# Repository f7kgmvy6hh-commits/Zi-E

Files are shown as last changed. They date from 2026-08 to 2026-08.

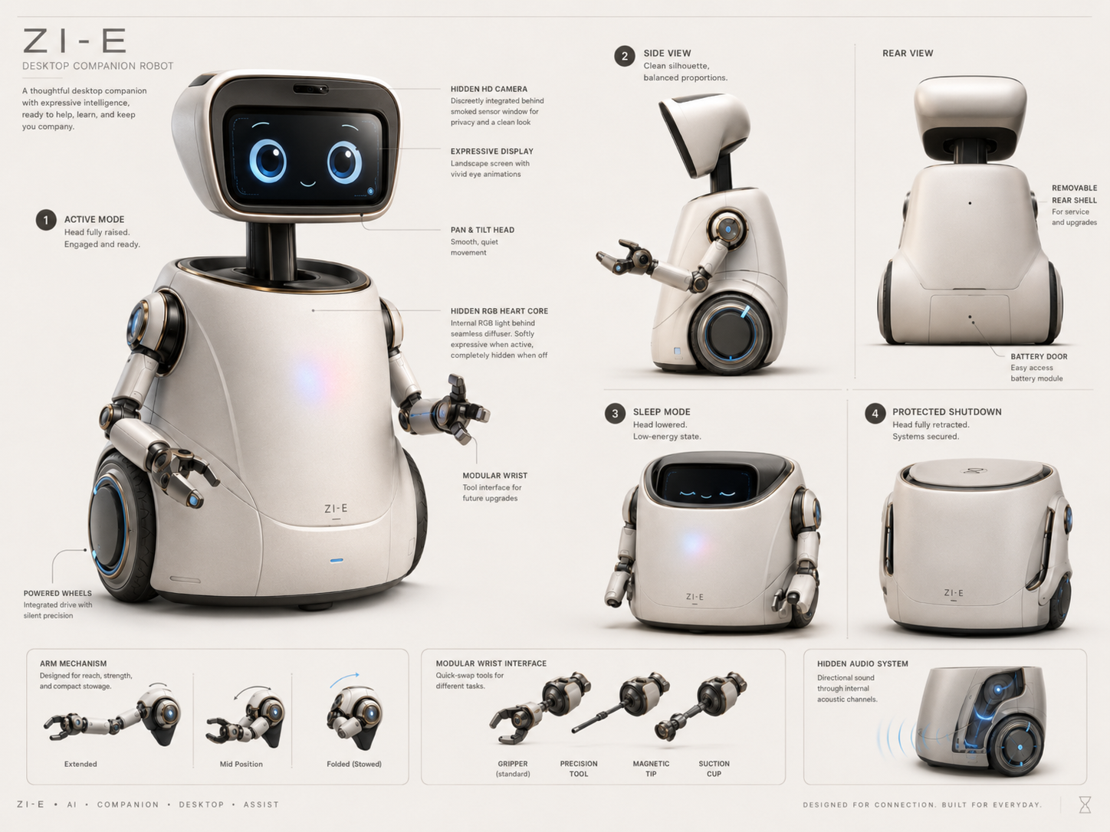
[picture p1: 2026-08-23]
assets/concepts/ZI-E_early_concept_board.png

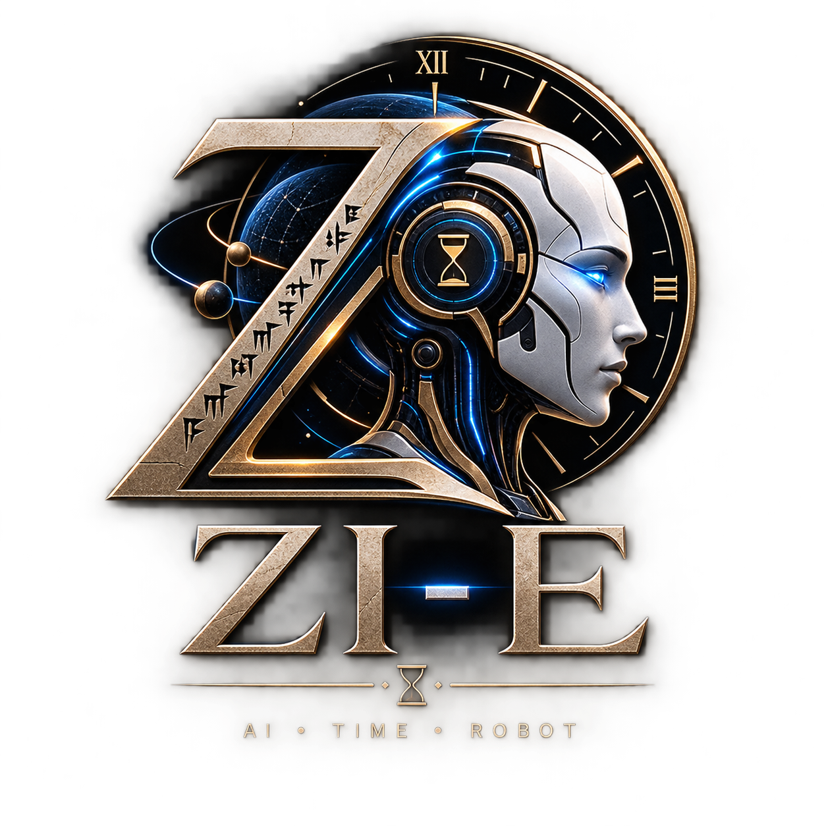
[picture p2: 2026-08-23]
assets/branding/ZI-E_AI_Time_Robot_Emblem.png

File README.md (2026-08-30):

# Zi-E

Zi-E is a modular desktop AI companion robot under active engineering development.
The repository contains the HostRuntime and Control Center foundations, bounded
semantic protocols, a physically inert ESP32-S3 Presence target, host-testable
firmware contracts, hardware evidence, and safety/commissioning gates.

## Current status

- Control Center: App 0.05, evidence-driven engineering cockpit.
- HostRuntime: development foundation and tests are active.
- ESP32-S3: the official ESP-IDF v6.0.2 generic Presence target cross-build passes.
- ESP32 physical binding: disabled; HW-002 has not arrived and is unverified.
- ESP32 flashing: not authorized and absent from the generic build workflow.
- STM32: official toolchain and physical target remain incomplete.
- Phase2B2: WAITING_FOR_VERIFIED_INPUTS.
- Physical commissioning: NOT_STARTED; first integrated power is NOT_AUTHORIZED.

See [Current State](docs/CURRENT_STATE.md) for the exact software and hardware truth.

## Architecture

```text
HostRuntime / AI brain
        authenticated, bounded semantic protocol
ESP32-S3 Presence Runtime
        bounded semantic controller-link boundary
STM32 Safety / Motion Authority
```

HostRuntime owns AI, planning, memory, providers, Hermes integration, semantic
coordination, and the Control Center. ESP32 owns the future network/media/face edge
but no final motion authority. STM32 owns motors, actuators, encoders, limits,
cliff/bumper/current supervision, E-stop, Motion Kill, safe stop, and final physical
motion acceptance or rejection.

A connection never grants motion authority. ACCEPTED does not mean EXECUTED. Face
behavior cannot originate movement. STOP/FREEZE/EMERGENCY_STOP remain deterministic,
bounded safety observations; physical stop confirmation belongs to the protected
STM32 path.

## Quick start

Windows setup creates a local virtual environment and a random bearer token in the
Git-ignored .env file:

```powershell
powershell -ExecutionPolicy Bypass -File .\scripts\setup.ps1
powershell -ExecutionPolicy Bypass -File .\scripts\start.ps1
```

The Control Center opens on the configured loopback address (default
http://127.0.0.1:8766/). The bearer token stays in page memory only; it is not stored
by the browser.

Run the App and script test suite:

```powershell
.\.venv\Scripts\python.exe -m pytest tests\app tests\scripts -q
.\.venv\Scripts\python.exe .\scripts\run_tests_fallback.py
```

Run the host firmware configure/build/tests with the fixed workflow:

```powershell
powershell -ExecutionPolicy Bypass -File .\scripts\firmware-workflow.ps1 -Action host-configure
powershell -ExecutionPolicy Bypass -File .\scripts\firmware-workflow.ps1 -Action host-test
```

Run the official generic ESP32-S3 build from an EIM-activated ESP-IDF environment:

```powershell
cd "C:\Users\mohamad alayan\Desktop\Zi-E"
eim run "powershell -ExecutionPolicy Bypass -File .\scripts\build-esp32.ps1"
```

This fixed action is **BUILD ONLY / NO FLASH / GENERIC_UNVERIFIED_ESP32S3**. It
accepts no board profile, port, credentials, flash action, or arbitrary command. A
successful build does not establish compatibility with HW-002 or any physical board.

## Documentation

- [Current State](docs/CURRENT_STATE.md) — concise active status and blockers.
- [Master Specification](docs/ZI-E_MASTER_SPEC.md) — product/architecture contract.
- [Modular Hardware Architecture](docs/MODULAR_HARDWARE_ARCHITECTURE.md) — authority
  and subsystem boundaries.
- [Open Items and Freeze Gates](docs/OPEN_ITEMS_AND_FREEZE_GATES.md) — evidence still
  required.
- [Engineering Method and Memory Loop](docs/ENGINEERING_METHOD_AND_MEMORY_LOOP.md) —
  mandatory review method.
- [Repository Map](REPOSITORY_MAP.md) — active and historical areas.
- [Firmware guide](firmware/README.md) and
  [ESP32 target guide](firmware/targets/esp32/README.md).

## Repository areas

- app/ — HostRuntime-facing Control Center, providers, models, and security bounds.
- firmware/ — shared contracts, host tests, and disabled physical targets.
- mechanical/ and electronics/ — active engineering artifacts and evidence.
- docs/ — current specifications, decisions, evidence, risks, and archives.
- scripts/ — fixed setup, validation, and build workflows.
- legacy/ — preserved historical snapshots/exports and untrusted reference material.

The root README is the human entrypoint, REPOSITORY_MAP.md maps paths, and
PROJECT_CONTEXT.md holds stable product context. Historical exports may preserve
contradictory old facts and never override active evidence.

## Hardware and safety

HW-002 is ordered, has not arrived, and remains unverified. The separately
bench-validated HW678 spare board is not HW-002; its memory, GPIO, power behavior,
and temporary bench wiring do not define a production profile. No camera, display,
audio, touch, RGB, wake, I2C, I2S, TWAI, power, or actuator pin is frozen by the
generic build.

No unrestricted physical motion or hardware API is exposed to AI, App, plugin, or
browser code. No integrated power or normal autonomous motion is permitted until the
physical evidence and low-power commissioning gates pass, including actual-state
confirmation.

## Provenance

XiaoZhi is a pinned engineering donor/reference, not Zi-E's identity, cloud
dependency, or motion-authority source. Imported code/assets require explicit
license and provenance review. Materials under legacy/ are historical and untrusted
unless independently promoted through the current engineering process.

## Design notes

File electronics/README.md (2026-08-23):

# Electronics

No final component list, wiring, pinout, battery topology, or power architecture is approved yet.

Legacy electronics material must be revalidated from primary datasheets.

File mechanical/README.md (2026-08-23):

# Mechanical

Current phase: concept-to-engineering transition.

Do not create final CAD until `docs/CURRENT_STATE.md` Design Freeze v0.1 envelope work has been completed.

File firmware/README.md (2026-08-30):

# ZI-E firmware

ZI-E firmware is split by responsibility while sharing stable, vendor-neutral contracts. The ESP32-S3 owns multimedia and presence hardware. The STM32 owns motion and safety-critical hardware. Laptop/phone behavior sends only safe, high-level commands.

## Layers

```text
AI / behavior
    -> api/SafeRobotCommands
    -> services
    -> core/HardwareRegistry (interfaces only)
    -> drivers/{esp32,stm32,stub}
    -> vendor SDK / hardware
```

- `include/zie/hal/`: stable hardware interfaces and shared value types.
- `include/zie/core/`: capability registry and hardware-profile declarations.
- `include/zie/extensions/`: centralized versioned extension manifest and capability-state contracts.
- `include/zie/services/`: reusable robot logic that depends only on interfaces.
- `include/zie/api/`: the only intended behavior/AI-facing command surface.
- `drivers/esp32/`: multimedia/presence bindings.
- `drivers/stm32/`: safety/motion bindings.
- `drivers/stub/`: deterministic host/bench implementations.
- `profiles/`: composition roots for `bench-minimal`, `stage1`, and `full-prototype`.
- `tests/`: host-side dependency and safety-boundary checks.

Concrete board drivers translate a stable interface into a vendor SDK. Vendor headers, GPIO, PWM, register access, bus addresses, and board pin identifiers stay inside the relevant driver implementation. Services and the AI-facing API must not include them.

## Motion command lifecycle

`core/MotionCommandLifecycle` is the Phase 2A transport-independent safety contract.
It identifies commands by source/session/sequence, permits only one active owner,
rejects duplicates without extending their lease, rejects stale or in-flight
replacement requests, enforces legal execution-state transitions, and detects lease
expiry using caller-supplied monotonic milliseconds. A transition at or after expiry
fails closed as `faulted` with `command_lease_expired`.

This class reports when a safe stop is required; it does not actuate hardware. The
STM32 integration must poll it from the local safety loop and execute/confirm the
physical stop. Cross-session authority, wire encoding, and link heartbeat behavior
remain Phase 2B work.

## Controller-link session

`link/ControllerLinkSession` is the transport-independent Phase 2B1 boundary. A valid
Hello establishes only a candidate session; motion authority remains unavailable until
the first valid heartbeat proves current liveness. It selects the lower compatible
protocol minor, binds liveness to an expected controller and peer boot session, rejects
duplicate/stale heartbeats without refreshing the deadline, and removes authority on
timeout or peer restart. A restarted peer requires explicit local renegotiation and a
fresh heartbeat, and the immediately retired boot session cannot be reactivated by a
delayed Hello.

Malformed, unexpected-controller, retired-session, and incompatible-version Hellos
are rejected without changing a healthy established session. Only a different boot
session presented as the configured expected peer is treated as a restart fault. This
limits unauthenticated Hello denial of service but is not authenticated replay defense.

The heartbeat timeout is verified configuration supplied by the composition root;
this scaffold does not choose one. Wire framing, payload bounds, integrity checks,
CAN/TWAI mapping, retry policy, and physical safe-stop integration remain Phase 2B2
and Phase 2C work.

## Extension manifest foundation

`extensions/ExtensionManifest` separates `HOST_PLUGIN`, `ASSET_PACK`,
`EMBEDDED_MODULE`, and `PROTECTED_SAFETY_MODULE` validation. Trust is supplied by the
future registry rather than claimed by a manifest. Typed permissions are requests, not
runtime grants; embedded and protected modules cannot request host permissions, and
asset packs cannot contain an entrypoint or permissions.

Declared, validated, and active capabilities are distinct sets. Validation requires
each set to be a subset of the preceding trust stage and prevents inactive, failed,
quarantined, disabled, or removed extensions from exposing active capabilities. This
is an in-memory contract only; loading, schema parsing, sandboxing, registry behavior,
and permission enforcement are not implemented.

All enum-bearing manifest, trust-context, and capability-state inputs are checked
against explicit supported domains before class/lifecycle semantics. Out-of-range enum
values fail closed; category trust boundaries do not rely on enum ordinal ranges.

## Hardware profiles

- `bench-minimal`: stub display, motion controller, battery, range sensor, and audio.
- `stage1`: requires the baseline plus STM32 safety sensing; camera and belly matrix are optional.
- `full-prototype`: requires the baseline plus camera, belly matrix, head motion, arms, and cliff/collision sensing.

Production profile factories intentionally remain unbound until exact hardware details are verified. Missing required capabilities fail profile validation instead of silently falling back.

## Host validation

```sh
cmake -S firmware -B build/firmware-host
cmake --build build/firmware-host
ctest --test-dir build/firmware-host --output-on-failure
```

This validates architecture and safe-command behavior only. It is not hardware commissioning. Before motion on assembled hardware, follow the repository's low-power commissioning and actual-state-confirmation rules.

## Physical target preparation

Disabled target boundaries live under `targets/esp32` and `targets/stm32`. They require
a reviewed profile under `board_profiles` and contain no guessed pins, clocks, buses or
ratings. Use `scripts/toolchain-doctor.ps1` and `scripts/firmware-workflow.ps1`; never
select a flash/program target by discovery order.
# Target architecture preparation

The ESP32 target supports an explicit `ZIE_UNVERIFIED_GENERIC_BUILD` real
ESP-IDF cross-build
with camera, display, audio, TWAI, production run and physical authority disabled. It
contains no pins and is not a physical board profile. Configure, compile, link, image
generation, and size reporting pass under the official ESP-IDF v6.0.2 toolchain;
flash remains unauthorized. See
`docs/ESP32_OFFICIAL_COMPONENT_PLAN.md`.

The future ESP32 target is a Zi-E Presence Runtime using official ESP-IDF components
behind a physically verified per-board binding. XiaoZhi ESP32 is a pinned engineering
reference, not vendored code, a cloud dependency, or an authority layer. The future
STM32 target remains the sole physical safety/motion authority. See
`docs/TARGET_ARCHITECTURE_FREEZE_CANDIDATE_V1.md` and the two semantic interface V1
contracts. Both production bindings remain disabled; no pins or CAN values are frozen.

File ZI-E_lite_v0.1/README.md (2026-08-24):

# ZI-E Lite Aluminum v0.1

**Build-now branch:** stationary, fixed-head, aluminum-body ZI-E for software/AI bring-up before buying the expensive mechanical system.

## Current source of truth
- No 3D printed structure.
- No arms, wheels, Pan/Tilt/Lift motors, laser, cliff sensors or motion MCU in this build.
- Fixed/removable head; nominal face tilt 7 degrees upward, adjustable only during assembly.
- Aluminum body sized to preserve future upgrade interfaces.
- Main electronics candidate: **Waveshare ESP32-S3-Touch-LCD-3.5B** (3.5-inch IPS capacitive touch + ESP32-S3R8 + 8 MB PSRAM + 16 MB flash + IMU + RTC + microphone/audio codec + battery management + camera interface).
- Camera: OV5640 on the board camera interface.
- Speaker: included 6 ohm / 1 W speaker.
- Emotion light: one hidden diffused RGB LED.
- Initial power: USB-C. Battery is optional and intentionally purchased later.

## Start here
1. Read `docs/MASTER_SPEC.md`.
2. Print `templates/ZI-E_Lite_v0.1_1to1_A4_CUT_TEMPLATES.pdf` at **100% / Actual Size**.
3. Verify the 50 mm calibration line before tracing any aluminum.
4. Read `docs/ALUMINUM_BUILD_GUIDE.md` before welding.
5. Read `electronics/WIRING_GUIDE.md` before connecting anything.

## Important
This is a **software-first prototype shell**, not the final mobile body. The full v0.3 mechanical architecture remains deferred, not deleted.

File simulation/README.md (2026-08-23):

# Simulation

Planned for mechanical/electrical/software prototype validation before full hardware purchase.

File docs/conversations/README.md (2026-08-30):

# ZI-E Conversation Archives

- `2026-08-31-maintenance-pass-continuation-validation.md` — continuation review,
  evidence-identity correction, archive integrity repair, and final validation matrix.
- `2026-08-31-final-bench-evidence-delta.md` — HW-008 independent RGB/DI bench pass
  and conservative unmapped touch-module investigation evidence.
- `2026-08-23_full_project_chat.md` — Initial project workflow, legacy policy, laptop/phone AI architecture, full concept-design evolution, head/sleep/shutdown system, body/wheels/arms/battery/audio/service decisions, concept images, and GitHub migration setup.

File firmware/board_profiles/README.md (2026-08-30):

# Reviewed physical board profiles

This directory intentionally contains no board profile. A profile may be added only
after arrival/physical review and must include `ZIE_BOARD_PROFILE_VERIFIED=TRUE` plus
reviewed provenance. Never add seller-only pins or placeholder values to satisfy a
build. `scripts/firmware-workflow.ps1` refuses target operations without such a file.

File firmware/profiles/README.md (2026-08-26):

# Hardware profile bindings

`BenchMinimalProfile` is executable now and binds deterministic stub drivers.

The `stage1` and `full-prototype` requirement sets are implemented by
`core::validate_profile`. Their production composition roots remain explicit TODOs
until verified board details and concrete drivers exist. Stage1 and full-prototype
require STM32 safety sensing. All bindings carry validated ownership as:

- ESP32-S3: Display, Audio, Camera, BellyLightMatrix.
- STM32: MotionController, Battery safety telemetry, safety RangeSensor instances,
  HeadMotion, Arms, SafetySensors.
- The head measurement RangeSensor may be ESP32-S3-owned when used only for
  presence/vision assistance; it must not substitute for STM32 safety sensing.

Do not place guessed pins, addresses, limits, or electrical parameters here.

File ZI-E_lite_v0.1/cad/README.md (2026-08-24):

# CAD
`ZI-E_Lite_v0.1_ASSEMBLY.step` is the nominal envelope model for packaging/visualization.
The manufacturing source of truth for hand-cut aluminum is the 1:1 PDF + DXF/SVG flat panels.
Because hand welding introduces fit-up and heat distortion, final seam trimming should be done on the actual shell rather than inferred from the STEP alone.

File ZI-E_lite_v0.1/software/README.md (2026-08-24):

# Software Bring-up Order

1. Flash factory/demo firmware and verify display + touch + IMU + RTC + audio.
2. Create ZI-E face renderer (LVGL) in landscape orientation.
3. Add touch events: wake, mute, simple settings, debug overlay.
4. Bring up OV5640 capture and local preview.
5. Bring up microphone capture and speaker playback.
6. Add Wi-Fi provisioning and laptop connection.
7. Implement host ZI-E daemon: WebSocket/HTTP status + camera/audio/session link.
8. Connect speech recognition, TTS, LLM and memory on the laptop.
9. Add the single RGB emotion state output.
10. Add diagnostics: board temperature/power state, Wi-Fi RSSI, camera status, audio status, RTC and battery state.
11. Only after the stationary software is stable, start the mechanical upgrade branch.

The API must be hardware-agnostic so the later full robot can keep the same high-level commands while replacing the stationary backend.

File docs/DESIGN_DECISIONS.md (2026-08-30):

# ZI-E Design Decisions — Concept v0.1

## 2026-08-31 — Evidence identity and maintenance validation boundary

- The independently tested HW678/S3-N16R8 board remains `SPARE-HW678` in the
  project evidence overlay. The repository does not explicitly prove it is the
  physical unit represented by procurement row HW-001, so no inventory-ID mapping is
  assigned pending a reviewed photo/order-to-unit link.
- Evidence validation checks the exact conservative state tuple for every surfaced
  hardware item. A changed or promoted state invalidates the complete evidence file
  and cannot pass readiness or commissioning.
- Historical move destinations retain prospective Git blob identity. Archive-local
  attributes preserve the three pre-existing byte-form exceptions without causing
  line-ending rewrites across the rest of the Lite export.
- HW-008 has an independent functional bench PASS for DI and RED/GREEN/BLUE/OFF using
  the ESP32 3V3 rail, a measured approximately 330 Ω series resistor, and temporary
  GPIO7. This does not verify final 5 V operation, freeze GPIO7, or complete integrated
  display/RGB commissioning; HW678 5Vin remains prohibited as an assumed 5 V source.

## 2026-08-30 — Superseding physical-evidence and Control Center truth boundary

- **Supersedes mistaken HW-002 presence language below:** HW-002 has not arrived and
  remains ordered/unverified. The present, independently bench-tested HW678 spare is
  a separate board; its 16 MB flash, 8 MB OPI PSRAM, GPIO, and rail observations
  cannot define HW-002.
- Do not map that bench record to inventory HW-001 without an explicit reviewed
  photo/order-to-unit link. Similar N16R8 descriptions are supporting context, not
  identity proof; the evidence record names the unit `SPARE-HW678` meanwhile.
- HW-017 is physically present and actively used as a bounded bench tool. That
  observation does not validate an exact model, fuse, CAT rating, or mains use.
- Current changing bench/software truth is carried by a small repository-owned,
  schema-validated evidence record. The Control Center accepts only the exact bounded
  schema and fails closed to UNKNOWN/NOT_RUN/NOT_AUTHORIZED; evidence presence never
  grants authority or passes commissioning.
- Repository metadata may be cached in-process for at most two seconds to reduce Git
  process creation. Live runtime, controller, power, safety, and commissioning state
  is not cached by this policy.
- Root historical bundles/exports and the former chronological Current State are
  preserved under legacy and docs/archive with manifests. Archive moves do not erase
  content or reduce existing Git history.

## 2026-08-30 — Fixed generic ESP32-S3 build remains physically inert

- The unverified ESP32-S3 profile may be configured, cross-compiled, linked, and sized
  without a verified board profile, while all physical bindings remain disabled.
- The fixed generic workflow accepts no caller arguments and contains no flash/monitor
  path. A build result never verifies HW-002 or authorizes first power.
- Embedded bounds are software ingestion limits, not physical timing, electrical,
  flash, or PSRAM claims.
- ESP-IDF's generic 2 MB flash-image default is accepted only to make a nonphysical
  build artifact. It is not a board declaration and must be replaced by verified
  evidence in any future HW-002 profile.

## Control Center 0.04 evidence-driven build decisions — 2026-08-29

- App version `0.04` reflects API/HUD changes; hardware evidence entry alone does not
  force App version churn.
- Purchased inventory, candidates, reviewed identity, and verified hardware remain
  separate. Exact identity suggests `MATCH_REVIEW_REQUIRED`; similarity suggests only
  `POSSIBLE_MATCH`; neither creates authority.
- The candidate catalog drives coverage/evidence requests but never seeds inventory.
- Readiness has robot authority `NONE`, cannot pass physical gates or authorize first
  power, and Phase 2B2 remains `WAITING_FOR_VERIFIED_INPUTS` for controller-link/CAN.

## Control Center V1 cockpit boundary — 2026-08-28

- The App is a 16-workspace operator/developer cockpit, not a runtime, registry,
  Hardware Profile authority, commissioning authority, or protected controller.
- Hardware telemetry is nullable and state-qualified. Simulator output is
  `SIMULATED`; repository entries remain `NOT_VERIFIED` or `VERIFY_ON_ARRIVAL`.
- At the 0.01 boundary, inventory upload was a bounded non-persistent preview. This
  historical limitation was superseded by 0.03's contained revisioned persistence;
  user text still cannot assert `VERIFIED`, bind a device/profile, or satisfy commissioning.
- Developer execution is a fixed no-argument allowlist with authentication, fixed
  working directories, timeout, bounded output and audit logging. Generic shell,
  arbitrary filesystem, raw hardware and unrestricted flashing APIs are forbidden.
- Physical commissioning gates have no self-certifying App mutation path. Future
  transitions require reviewed physical evidence; execution confirmation remains
  authoritative HostRuntime/controller feedback only.

This document captures the design decisions made so far. Dimensions are not final unless explicitly stated.

## 1. Overall category and personality

- ZI-E is a **desktop companion robot**.
- It should not be extremely small or large.
- Exact size is secondary to good proportions, internal service space, battery capacity, and a clean desktop presence.
- Visual direction: **cute + futuristic + premium**, but believable and buildable.
- It should have its own identity rather than being a WALL-E or BMO copy.

## 2. Overall body shape

**Approved direction: Hybrid body.**

- Wider toward the bottom.
- Slightly narrower through the middle.
- Soft transitions toward the upper head opening.
- Rounded, non-boxy edges.
- Front chest is **gently convex** to give the robot personality.
- Rear remains sculpted and attractive; it must not look like a flat electronics access panel.

## 3. Head

### Shape
- Custom soft-trapezoid / futuristic head.
- Wider near the top and slightly narrower toward the bottom.
- Rounded edges.
- Balanced head size, not oversized-cute or tiny.
- Target proportion: roughly **55–60% of body width** as a concept guide.
- Head should be relatively low/wide to suit the landscape face and retraction.

### Face
- **One landscape digital screen.**
- Face is digital; no mechanical eyes or eyelids.
- Custom bezel around the display.
- Digital expressions can change without extra mechanics.

### Camera
- Camera belongs in the **top-center region above the screen**.
- It should be highly concealed.
- Preferred appearance: hidden behind a dark/smoked sensor window or very discreet slit.
- Camera remains usable in Active and Sleep modes.
- It becomes protected/hidden in full shutdown.

## 4. Head and neck motion

### Neck
- One central, short, relatively broad neck.
- Internal wiring should route through the neck where practical.

### Head motion
- Pan.
- Tilt.
- Vertical retract.

### Retraction mechanism
**Approved concept:** a vertical slider on internal guide rails.

Avoid a complicated telescopic neck for Version 1.

## 5. Operating poses

### Active Mode
- Head fully raised.
- Neck visible.
- Pan/Tilt available.
- Full visual interaction.

### Sleep Mode
- Head lowers enough for the neck to disappear.
- Display remains visible.
- Camera remains functional.
- Screen may show sleepy eyes, time, battery, or other low-energy information.
- Arms rest in a relaxed state.
- Hidden RGB heart/core uses a slower, dimmer pulse.

### Protected Shutdown
Goal: **maximum protection + minimum physical volume + attractive compact form**.

- Head retracts significantly deeper than Sleep.
- Screen and camera become physically protected.
- Head should be almost completely hidden inside the body.
- Top opening follows the head's shape.
- Body has a slight inward slope and a subtle protective rim around the head opening.
- Arms retract/fold into side recesses.
- Wheels can be manually tucked/folded inward.
- Robot should resemble a compact protected pod rather than a robot merely switched off.
- RGB heart/core turns off.

## 6. Top body opening

- Opening follows the custom head shape rather than being a generic rectangle.
- Upper surface slopes slightly inward toward the opening.
- Very subtle raised/protective rim.
- Aim for a nearly closed/flush-looking protected shutdown profile.

## 7. Chest light / “heart”

- RGB status/emotional light on the front chest.
- Location should be easy to see.
- **It must be hidden when off.**
- No obvious external heart badge when inactive.
- Preferred implementation concept: internal RGB light behind a flush, frosted/seamless diffuser integrated into the convex chest.
- Active: subtle expressive pulse.
- Sleep: slower/dimmer pulse.
- Shutdown: off.
- Future status colors may indicate charge/errors without making the chest look like a dashboard.

## 8. Drive system

### Approved base architecture
- Two **fixed powered wheels**, independently driven.
- Differential drive.
- Hidden passive support point/caster underneath.
- Zero-radius turning using opposite wheel directions.
- No swerve/360-degree steering in Version 1.
- No motorized ball drive.
- No Mecanum/omni base in Version 1.

Reasoning: sideways travel is not worth the extra mechanical complexity, size, wiring, backlash, and failure points for this companion robot.

The independently moving head can maintain gaze while the body reorients.

### Wheel appearance
- Semi-exposed.
- Roughly half visually integrated into the housing and half visible as a concept direction.
- Medium-to-large visual proportion, approximately **35–40% of body height** as a starting proportion only.
- Style: **hidden mechanical + futuristic**.
- Motors/axles/wiring remain concealed.
- Wheel pods should look designed into the body, not attached afterward.

### Protected shutdown wheels
- Manual inward tuck/fold is acceptable and desired.
- No powered wheel-fold mechanism for Version 1.
- Robot may rest on hidden rubber feet when wheels are tucked.

## 9. Arms

The arms are **functional and expressive**, not decorative only.

### Placement
- Shoulder mounts are high on the sides.

### Joints / functions
- Shoulder joint.
- Elbow joint.
- Telescopic forearm, one extension stage.
- Compact wrist/tool interface.
- Compact adaptive two-finger gripper as the normal/default hand.

### Arm reach
- Normal arm length should look proportional in daily use.
- Forearm extends only when extra reach is needed.
- Concept target: extension to roughly 135–150% of normal length, subject to engineering validation.

### Hand/gripper
- Two-finger adaptive gripper.
- Rounded and compact.
- Designed for light tasks such as:
  - holding small/light objects;
  - pressing buttons;
  - passing an object;
  - holding a stylus through an adapter;
  - pushing/pulling light items.

This is not intended as a heavy industrial manipulator.

### Wrist / tool ecosystem
- Manual quick-swap tool system for Version 1.
- Interface should be designed **auto-ready** for a possible future docking/tool-changing system.
- Future tool examples: stylus, sensor, magnetic pickup, suction tool, small light, custom tools.
- Mechanical lock, power/data contacts, and alignment concept will be engineered later.

### Arm shutdown sequence
1. Retract telescopic forearm.
2. Close gripper.
3. Return wrist to safe position.
4. Fold elbow.
5. Tuck shoulder.
6. Entire arm nests into a shaped side recess.

The recess should look like a natural body design line rather than an ugly cavity.

## 10. Internal service architecture

### Exterior vs structure
ZI-E uses:
- cosmetic outer shell;
- structural internal core/frame;
- modular internal subsystems.

The cosmetic shell should not be the sole load-bearing structure.

### Rear access
- Sculpted rear appearance.
- Rear shell should be removable for major service.
- No essential wiring should live on a removable cosmetic cover where it must be unplugged every time.
- Seams should follow design lines.

### Internal modularity
Use multiple modules placed in their optimal functional locations rather than one giant electronics tray.

Candidate zones:
- top: head lift / head motion;
- center: controller and communication;
- bottom-center: battery/power;
- sides: wheel modules and arm mechanisms;
- front peripheral: hidden RGB/core and forward sensors.

Modules should be removable independently where practical.

## 11. Battery concept

- Large battery capacity is a priority.
- Long runtime matters more than shrinking the body by a few centimeters.
- Battery bay should support later capacity upgrades.
- Battery lives low and central for a low center of gravity.
- Preferred access: **camera-style quick-release battery cartridge/door**.
- Best concept location: lower rear, on a subtly angled flush panel.
- User should not need to turn the robot upside down to access it.
- Door should not visually damage the rear design.

Battery chemistry/cell configuration is NOT yet selected.

## 12. Audio

- No ugly front speaker grille.
- Speaker should be hidden inside the body.
- Use an internal acoustic chamber and carefully designed vents/ducts.
- Consider symmetric output paths and desk-surface reflection.
- Do not assume “more holes = better sound”; final acoustic dimensions depend on the real speaker/enclosure.
- Keep speaker physically separated from the head microphone as much as practical.
- Software echo cancellation may be used later.

## 13. Exterior cleanliness

From the front, visible elements should be minimal:
- digital face;
- subtle camera location;
- hidden-when-off RGB heart/core;
- intentional body surfaces.

Speaker openings and sensors should be hidden in the best functional locations using vents, dark windows, seams, or lower/rear openings.

## 14. Serviceability principle

ZI-E should be upgradeable without redesigning the whole robot.

Examples:
- controller replacement;
- battery upgrade;
- wheel module replacement;
- arm/tool upgrade;
- speaker change;
- added sensor;
- future phone integration.

Prefer standardized internal mounting patterns and connectors.

## 15. Concept-image status

The repository contains concept sheets under `assets/concepts/`.

Important correction applied to later concept:
- camera made much less visible;
- RGB chest light made concealed/seamless when off.

Images are **visual direction references**, not dimensionally accurate CAD.

## 2026-08-23 — Hidden Belly Light Matrix and pre-purchase failure-harvest
**Decision:** Add a hidden RGB belly matrix behind a flush secret-until-lit optical insert. Prototype with IS31FL3741 13×9, but reserve larger custom matrix keepout in CAD. It is non-safety multimedia and must fail dark.

**Decision:** Add a permanent Open-Source Harvest Loop. Reachy Mini, LeRobot SO-101, OpenArm, Stretch, MoveIt/Nav2 and MuJoCo failure patterns are used to create preventive tests and architecture changes before bulk part purchase. Immediate changes include safe commissioning, explicit command execution state, single motion arbiter, bus/cable fault containment, dynamic payload/stability model, dynamic collision zones, diagnostic tooling and explicit simulation inertials.

## 2026-08-23 — Project v0.3 dedicated head laser rangefinder
- Add one dedicated forward single-point Class-1 ToF laser rangefinder in the head sensor brow.
- Primary candidate: VL53L1X, because up-to-4 m / 50 Hz is sufficient for a desktop companion and the final bare package is extremely small.
- Camera remains centered; rangefinder is offset and software must calibrate the camera/rangefinder extrinsic relationship.
- Rangefinder is for measurement/vision assistance and does **not** replace local STM32 cliff/proximity/bumper safety.
- The optical brow/window must be validated for ~940 nm transmission and crosstalk; arbitrary dark plastic is not accepted without test.
- TF-Luna becomes the intentional backup if >4 m range or >50 Hz is required; TFmini-S only if a real longer-range requirement appears.

## 2026-08-27 -- Modular hardware firmware boundary

- Preserve ESP32-S3 ownership of multimedia/presence hardware and STM32 ownership of
  safety/motion-critical hardware.
- AI/behavior uses a safe high-level command facade and never directly controls GPIO,
  PWM, registers, vendor APIs, motors, or individual actuators.
- Hardware is supplied through stable capability interfaces and explicit profile
  bindings. Optional hardware is represented as an absent capability, not hidden by a
  guessed or silent production fallback.
- Production motion remains gated by verified low-power commissioning and actual-state
  confirmation. The initial code is an architecture scaffold, not a hardware freeze.

## 2026-08-27 — Phase 2A motion lifecycle foundation

- Establish the command lifecycle as a transport-independent core before selecting a
  CAN/TWAI wire encoding.
- Identify motion commands by source, boot/session, and sequence; never use receipt
  order alone as proof of a new command.
- Permit one active motion command owner per subsystem. Duplicates are idempotent and
  do not renew leases; implicit replacement of an in-flight command is rejected.
- Check the monotonic lease on every state-changing call. Expiry is a local fault that
  requires a physical safe stop and later state confirmation by STM32.
- Defer cross-session authority negotiation, replay history, wire framing, heartbeat,
  and controller-reboot handling to Phase 2B.

## 2026-08-27 — Phase 2B1 controller session and liveness

- Negotiate controller compatibility by independently versioned protocol major/minor;
  a major mismatch fails closed and the negotiated minor is the lower supported value.
- Bind an active link to the configured peer controller and its nonzero boot session.
  A changed boot session removes motion authority and requires explicit local
  renegotiation; receipt of a new hello alone cannot silently replace the peer.
- A compatible expected-peer Hello establishes only a candidate session. Motion
  authority remains unavailable until the first valid bound heartbeat proves liveness;
  every renegotiated session requires a fresh heartbeat.
- Reject malformed, unexpected-controller, retired-session, and incompatible-version
  Hellos without mutating a healthy established session. Only a different boot session
  from the configured expected peer triggers a restart fault. This reduces trivial
  unauthenticated Hello denial of service without claiming authentication.
- Duplicate, stale, wrong-session, and invalid heartbeats do not renew liveness.
- Supply the monotonic heartbeat timeout from verified configuration. Do not invent a
  production timeout in reusable protocol code.
- Defer wire encoding, CAN/TWAI framing, integrity selection, and physical safe-stop
  binding until bus analysis and bench evidence exist. Long-lived authenticated replay
  protection remains explicitly open for Phase 2B2.

## 2026-08-27 — Extension manifest and capability trust foundation

- Treat `HOST_PLUGIN`, `ASSET_PACK`, `EMBEDDED_MODULE`, and
  `PROTECTED_SAFETY_MODULE` as separate execution models with class-specific validation.
- Assign trust from the registry/install source; never accept a manifest's claim that it
  is built-in, signed, or otherwise trusted.
- Treat requested permissions as declarations for a future deny-by-default enforcement
  layer, not grants. No raw actuator/safety-bypass permission exists; host motion access
  means Safe Robot API requests only.
- Keep declared, validated, and active capabilities separate. A manifest claim cannot
  populate either validated or active state, and inactive lifecycle states expose none.
- Version extension package, Plugin API, and manifest schema independently.
- Keep the current implementation as an in-memory validation contract. Parsing,
  loading, sandboxing, signatures, registry state transitions, and configuration
  activation require later reviewed foundations.

## 2026-08-27 — Device identity foundation

- Keep extension/package identity, physical manufacturer/model/serial identity,
  registry-generated logical instance identity, controller identity, and hardware
  profile binding as separate typed domains.
- Never derive stable identity from display name, USB path, COM port, IP address, CAN
  address, discovery order, or another transport/location observation.
- Represent devices without trustworthy serials using explicit registry-generated
  provisional-local identity and provisional trust. Promotion/rebinding is deferred to
  a future explicit migration workflow.
- Fail closed on duplicate physical or logical identities, conflicting provenance,
  unknown enum values, plugin-assigned controller/profile bindings, or changes after
  activation.
- Reserve protected STM32 safety-controller identity for registry assignment to
  built-in-trust extensions. Identity does not confer capabilities or permissions.
- Treat owning package, controller assignment, hardware-profile assignment, and
  extension trust as external registry validation context. Candidate records carry no
  authority flag and must exactly match that context.

## 2026-08-27 — In-memory extension registry and activation

- Accept an extension record only after manifest and device-identity validation under
  external registry assignment of package ID, trust, controller, and hardware profile.
- Reuse the shared lifecycle vocabulary and permit only explicit transition edges.
  Invalid/unknown transitions do not mutate registry state.
- Preserve removed records as in-memory tombstones. Duplicate packages and conflicting
  physical/logical identities fail closed.
- Resolve a capability only from active/degraded records after declared-to-validated-to-
  active subset checks. Reject activation when another live provider would make
  ownership ambiguous.
- Clear active capabilities synchronously on inactivity, failure, quarantine, disable,
  or removal. Capability ownership includes package and logical device instance.
- Registry acceptance grants no permission and exposes no raw hardware-control path;
  plugin motion remains semantic Safe Robot API requests only.
- Forbid generic lifecycle transition into `ACTIVE`. Both initial activation and
  degraded recovery must enter through capability activation after explicit
  inactive/activating states.

## 2026-08-27 — Transactional configuration foundation

- Separate declared, staged, validated, and active configuration. A failed candidate
  never mutates the prior active snapshot; rollback removes only staged/validated work.
- Bind every request to external authoritative package, logical device instance, and
  hardware-profile identity. Reject stale/nonzero revisions; assign a new registry
  generation only on successful commit.
- Permit commit only for inactive, active, or degraded owners. Quarantined, disabled,
  failed, activating, installed, and removed extensions cannot activate configuration.
- Configuration cannot grant permissions, trust, capabilities, controller/profile
  ownership, or safety authority. Reject raw GPIO/PWM/register/actuator/driver/safety
  bypass/CAN namespaces; hardware-affecting values remain semantic only.
- Require explicit inclusive signed 64-bit bounds for every bounded integer. Parse
  exact base-10 text without coercion; accept booleans only as lowercase `true` or
  `false`.

## 2026-08-27 — Semantic Robot API and command/event/state separation

- Define plugin-facing operations as typed semantic intents with package/device,
  session, and sequence identity. Map each command type to a fixed active capability;
  callers cannot choose their authorization requirement.
- Accept commands only from exact active registry providers. Quarantined, disabled,
  removed, failed, degraded, or inactive issuers cannot submit. Protected STM32 safety
  operations remain internal.
- Treat events as immutable occurrence records with no command or state side effect.
  Treat state as generation-ordered read-only snapshots written only through an
  authoritative core path.
- Keep raw motor setpoints, PWM, GPIO, registers, actuator ownership, raw CAN frames,
  and safety bypass outside the semantic command vocabulary.

## 2026-08-27 — Authoritative sessions, resilient events, and virtual robot

- Treat a command-carried session number as an identifier, never as authority. Only an
  authoritative core operation can bind or replace the active session for an exact
  registry package/logical-device pair; replacement permanently retires the prior ID.
- Keep replay ordering per authoritative session. Unknown, zero, mismatched, retired,
  duplicate, and stale session/sequence combinations fail closed.
- Bound every subscriber queue and expose deterministic `drop_newest` overflow instead
  of allowing silent memory growth. Recheck lifecycle/capability eligibility at publish
  and delivery, and isolate callback exceptions from other subscribers.
- Allow the virtual robot to consume only opaque accepted-command tokens. Acceptance,
  simulated execution, authoritative state mutation, and immutable event publication
  remain distinct steps; simulated failures preserve relevant state.
- Keep this host-only model outside physical safety claims. STM32 interlocks,
  commissioning, drivers, actual-state confirmation, scheduling, transport, and CAN
  remain separate future work.

## 2026-08-27 — Event delivery repair and provider resilience foundation

- Retain a failed event at the head of its subscriber queue for a configured bounded
  number of delivery attempts. Dead-letter it exactly once at exhaustion and expose a
  saturating per-subscriber count; never consume another subscriber's copy.
- Define LLM, STT, TTS, and wake contracts as vendor-neutral semantic values. Real
  networking, secrets, audio data/drivers/codecs, and provider SDKs remain excluded.
- Bind every provider to an exact registry package, logical device, manifest category,
  and unique kind-prefixed active capability. Recheck authorization at every call so
  lifecycle or capability revocation fails closed.
- Preserve unambiguous exact-capability ownership with distinct provider-instance
  capabilities. Provider order is explicit, provider count and attempts are bounded,
  and malformed responses or exceptions cannot bypass validation or extend failover.
- Provider outputs confer no Robot API, state mutation, safety, hardware, or raw
  actuator authority.

## 2026-08-27 — Typed provider routing and data-only presentation packs

- Require every provider invocation to name an exact semantic capability. Separate
  shared semantic routing capability from each provider's unique registry capability,
  preserving both deterministic failover and unambiguous registry ownership.
- Preserve bounded typed diagnostics for temporary/permanent failure, malformed
  response, provider exception, authorization loss, and capability mismatch. A
  successful fallback retains earlier failures; exhaustion retains its final cause.
- Keep face and sound packs data-only `asset_pack` records with authoritative package,
  version, logical-device, profile, schema, category, lifecycle, and capability checks.
  Packs cannot declare executable entrypoints, permissions, trust, or hardware control.
- Permit one selected face and one selected sound pack per presentation context.
  Replacement is deterministic and every use rechecks lifecycle/capability revocation.
- Route only accepted semantic expression, speech, and cue tokens into the presentation
  engine. State changes use the authoritative core; display/audio implementations and
  all raw hardware interfaces remain outside the layer.

## 2026-08-27 — Context-authoritative pack activation correction

- Keep pack declaration/validation state global to the data record and keep activation
  exclusively in bounded per-context selections. A pack may serve multiple contexts;
  replacing one selection cannot alter another.
- Make missing-context queries read-only and fail closed. When use-time registry
  reauthorization detects revocation, purge the affected pack from every context.
- Require explicit contextual activation after valid registry lifecycle recovery;
  never infer or restore selection from global pack state.

## 2026-08-28 — Plugin SDK and stable extension host boundary

- Publish only independent SDK DTOs and abstract semantic service/context interfaces.
  Keep the extension host and `AuthoritativeRobotCore` internal.
- Negotiate an explicit inclusive SDK contract range against the host-supported range.
  Reject zero/reversed ranges, incompatible majors, unsupported future versions, and
  unknown domains/capabilities; never infer future compatibility.
- Issue identity, trust, profile, capabilities, command session, sequence, and
  activation epoch from the host. Extension initialization receives no active
  capabilities or services.
- Reauthorize every SDK call against the live registry and fixed service capability,
  then route through the existing subsystem checks. SDK adapters confer no extra
  authority.
- Invalidate an activation epoch before suspension, failure, quarantine, or removal.
  Recovery returns only to inactive and requires a new activation/context/epoch.
- Bind each SDK epoch to a monotonic registry authorization generation that changes on
  activation and every revocation. Contain all extension callback exceptions; a
  throwing activation is failed and cannot leave usable handles.
- Revoke every issued context and tracked event subscription when the extension host
  is destroyed, so a retained adapter cannot outlive host authority or dereference a
  released backend.
- Supersede the earlier permanent package-tombstone rule narrowly: explicit full
  re-registration with a new logical instance identity may replace a removed registry
  record, but never revive it. Old host objects, contexts, service handles, epochs, and
  command sessions remain retired.
- Give executable SDK contexts only to host plugins. Asset packs stay data-only;
  embedded/protected modules stay outside the third-party host; provider/wake
  categories cannot receive semantic motion; no protected-safety or raw-control SDK
  domain exists.
- Expose configuration only as copied reads and typed stage requests with a host-built
  authoritative binding. Validation/commit remains transactional core authority, and
  identity/authority/raw-control namespaces remain forbidden.

## 2026-08-28 — Context snapshots and authoritative hardware-profile resolution

- Define every Plugin SDK `ExtensionContext` as an immutable issuance snapshot.
  Retained snapshots may preserve historical metadata, but their handles are
  epoch-bound and fail stale after revocation. The host's current-context query
  replaces active metadata with a zero-grant inactive/failed/quarantined snapshot,
  returns null after removal, and issues a fresh context only after explicit
  activation.
- Treat profiles as trusted, versioned semantic requirement sets resolved only
  against registry-authoritative device identity and lifecycle. Resolution uses exact
  hardware-profile binding, category, active validated capability, protected
  ownership, logical device, and authorization generation; ambiguity fails closed.
- Make activation atomic. Revocation invalidates the selected result and no spare is
  silently rebound; explicit re-resolution and reactivation are required.
- Exclude transport identity, GPIO/PWM/register/setpoint data, raw actuator control,
  and safety bypasses from profile content. Discovery, parsing, drivers,
  commissioning, persistence, and transport remain deferred.

## 2026-08-28 — Authoritative host runtime and safe recovery intent

- Keep orchestration internal and downstream of every existing subsystem authority.
  Startup establishes stopped semantic state, then orders profile, protected safety,
  extensions, and optional services. No coordinator call bypasses subsystem checks.
- Derive requiredness only from the trusted startup plan and fixed core-domain policy.
  Required or protected failure fails the runtime; explicitly optional failures may
  degrade it without granting authority.
- Revoke hosted extension epochs in reverse startup order before deactivating profile
  authority on shutdown or required failure.
- Treat checkpoints as bounded copied intent, never authority. Exclude sessions,
  handles, leases, setpoints, heartbeat state, command sequence authority, and safety
  bypass state.
- Split recovery into explicit prepare and complete phases. Re-resolve and compare the
  exact prior device set before profile/extension activation; revalidate configuration
  generations and presentation selections; reject substitution and bound retries.

## 2026-08-28 — Package security and update authority

- Keep package ID, version, and content identity distinct; transport/path is never
  identity and package declarations never grant trust or protected ownership.
- Updates and rollback traverse registry generation replacement and ordinary
  ExtensionHost activation, issuing fresh epochs and never resuming motion.
- Protected safety remains built-in-only; asset packs remain data-only; capability
  expansion needs explicit registry validation.
- Watchdog output is semantic only and plugin credentials are opaque owner handles.

## 2026-08-28 — Final software foundation freeze candidate

- Freeze one authority chain: package policy establishes eligibility; registry owns
  identity/trust/capabilities; profile manager owns exact resolution; ExtensionHost
  owns executable epoch/context/session issuance; HostRuntime only coordinates.
- Keep LLM, STT, TTS, and Wake as independent modality chains with exact semantic
  capabilities, authoritative ordered priority, bounded typed failover, and current
  registry authorization on every attempt. A provider cannot self-promote and a
  temporary fallback does not alter future primary eligibility.
- Freeze VirtualRobot only as the software integration contract. It cannot satisfy a
  physical commissioning gate or prove that an accepted command executed in hardware.
- Freeze the future App as a consumer of public/semantic services. It cannot bypass
  HostRuntime, registry, ExtensionHost, profile, package, or protected-safety checks.
- Adopt the Prototype P1 commissioning progression and require separate operator/
  physical evidence for every physical transition. Autonomous motion remains outside
  P1 and prohibited before all later safety gates.
- Keep all CAN/wire values and received-part-dependent pins, interfaces, dimensions,
  loads, timing, electrical limits, and physical performance explicitly unfrozen.

## 2026-08-28 — Zi-E V1 local command-center boundary

- Implement the laptop command center as a thin authenticated operator/UI layer around
  one persistent Hermes session; it is not another agent, tool loop, memory authority,
  or provider credential owner.
- Bind only to validated loopback and require bearer authentication for every API and
  event connection. Never expose Hermes, OAuth, ElevenLabs, or provider secrets to the
  browser; structurally redact logs and cloud-bound speech text.
- Expose narrow health/state/settings, Hermes chat, semantic robot-state, E-stop,
  voice-control, and event surfaces. A HUD panel does not imply a generic terminal,
  browser, filesystem, or actuator API.
- Keep robot state deterministic and fail closed. E-stop is reachable from every
  state; active host modes have a dead-man deadline; every command records source,
  UTC timestamp, semantic target, timeout, and result. Host acceptance is never
  physical execution confirmation.
- Default to real/non-simulator mode with null robot telemetry. Simulator data must be
  explicitly enabled and labeled and cannot satisfy commissioning evidence.

## 2026-08-28 — Zi-E V1 Hermes and voice execution

- Invoke Hermes 0.20.6 as `chat --continue <stable-name> --create-if-missing -q
  <message> -Q --source tool` and preserve one named session.
- Superseded: prompt-complexity routing between MiniMax and OpenAI is not provider
  authority. Send ordinary requests to the configured LLM primary (defaulting to the
  OpenAI-capable Hermes model), and let explicit `/model` requests bypass App
  selection. Bounded fallback remains modality-specific HostRuntime policy;
  `smart_model_routing` is only a setup placeholder and is not consumed.
- Stream redacted TTS in bounded chunks, centralize ElevenLabs voice/model, retain
  Zi-Nanami fallback, and cancel remaining work wherever the generator can observe it.

## 2026-08-28 — Current App/STT reconciliation

- Treat the current Python command center as a simulator/operator prototype, not a
  HostRuntime implementation or physical authority. A real target stays unavailable
  until the App consumes HostRuntime/public semantic services and commissioning gates.
- Keep OpenAI-capable providers preferred when configured and authorized, separately
  for LLM, STT, TTS, and Wake. Existing local Whisper, ElevenLabs, and Zi-Nanami
  adapters are fallback/available implementations; they cannot set authoritative
  priority or widen capabilities.
- Isolate native local Whisper execution in a bounded subprocess with a strict typed
  result contract. Ordinary STT/TTS never depends on Codex development authority.
- Fail closed when the App is configured for a real target without a commissioned
  HostRuntime/public-semantic adapter: retain `DISCONNECTED`, reject ordinary state or
  motion commands, and represent E-stop only as `requested_not_delivered`. A config
  flag cannot create physical authority or execution confirmation, and no event may
  label an unavailable target as physical.

## 2026-08-28 — App semantic HostRuntime adapter and honest status freeze

- Make `HostRuntimeAdapter` the App's only future real-target boundary. Its surface is
  copied status, closed semantic command request/response, semantic E-stop request,
  and polling; it contains no raw hardware or authority-mutation method.
- Distinguish simulation, real-target-unavailable, and reserved future-real-target.
  Bind every future-real response to current adapter target mode, positive authority
  generation, and session; a mid-request change fails closed before execution events.
- Distinguish requested, accepted, rejected, and confirmed phases; delivery and
  physical confirmation are independent. Only runtime feedback may assert physical
  confirmation. Simulation never does.
- Expose profile/configuration/presentation/provider/extension visibility honestly.
  Missing capability-scoped HostRuntime operations are `not_exposed` or unavailable,
  never decorative authority. Do not silently rebind devices or profiles.
- Keep App provider status separate for LLM/STT/TTS/Wake, exact-capability and ordered.
  Configuration is not authorization; report `not_verified` until a live HostRuntime
  check exists. Fallback is bounded and non-sticky in deterministic contract tests.

## 2026-08-28 — Prototype P1 physical source-of-truth contract

- Use current repository decisions/CAD as design authority and the reviewed future
  purchased-parts sheet, label photos, datasheets and measurements as physical-article
  authority. Archived/legacy CAD and older BOM assumptions cannot silently return.
- Treat all current component choices as documented candidates, undecided classes or
  `VERIFY_ON_ARRIVAL`; no current repository row is proof of received hardware.
- Keep v0.3 CAD numeric envelopes/performance as model parameters and estimates until
  received-part fit and physical tests replace them. Concept images have no dimensional
  authority.
- Preserve ESP32 multimedia/presence versus STM32 protected safety/motion ownership.
  Physical drivers remain built-in/protected; App/plugins/providers receive semantic
  capabilities only.
- Require the ordered logic-only, sensor-by-sensor, one-restrained-actuator-at-a-time
  commissioning package. VirtualRobot/software success cannot pass physical gates.
- Keep Phase 2B2 `WAITING_FOR_VERIFIED_INPUTS`; freeze no CAN/pin/connector/current/
  fuse/wire/regulator/timing/safe-stop value without reviewed evidence.

## 2026-08-28 — Zi-E HUD plugin presentation

- Use an original cinematic robotics-control visual language: graphite surfaces,
  cyan/ice-blue information, amber caution, and red emergency states. Do not copy
  Marvel/JARVIS branding, assets, phrases, or layouts.
- Treat HUD panels as host-registered plugins with declarative identity, permission,
  status text, and event subscriptions. The current registry is intentionally a
  lightweight browser presentation layer, not a privileged executable sandbox.
- Keep privileged actions behind the authenticated Zi-E backend. Plugin panels cannot
  access Hermes credentials, provider keys, arbitrary environment values, raw actuator
  control, or safety bypasses.
- Reserve port `8765` for the existing Zi-Nanami service and run Zi-E on loopback
  port `8766`.
- Enable `ZIE_SIMULATOR=true` for current host-only integration testing. Simulator
  telemetry is not physical evidence and must remain clearly labeled.
# 2026-08-29 — Deliberately slow Control Center product versioning

- `0.01` identifies the structural Project Cockpit foundation at `1c1cf43`.
- `0.02` identifies functional workspaces and safe fixed developer tools.
- Subsequent meaningful stages increment by `0.01`; `1.00` is reserved for a much
  later genuinely integrated/release-capable Zi-E system.
- Product/App versioning is independent from protocol, SDK, package-schema, CAD, and
  other compatibility versions with their own technical meaning.

# 2026-08-29 — Preview semantics and developer authority remain separate

- Camera test frames, face/RGB previews, drive previews, and actuator commissioning
  previews are process-local development functions. They never satisfy physical gates
  and never emit `PHYSICALLY_CONFIRMED`.
- Browser developer requests select one fixed action identity only. Executables,
  arguments, working directory, and allowed log location are server-owned; developer
  actions have robot authority `NONE`.
# 2026-08-29 — Control Center 0.03 inventory compatibility and truth boundary

- The existing 32-field CSV remains the interchange schema; 0.03 metadata is stored
  separately in application-owned ignored runtime state.
- Purchased inventory starts empty. Design candidates remain reference-only and are
  never converted to purchased, received, reviewed, or verified automatically.
- Every persisted mutation uses optimistic revision checking, validation, atomic
  replacement, and a bounded prior revision. Removal is a tombstone.
- Physical `VERIFIED` is a guarded explicit engineering-review transition requiring
  received status, exact identity, reviewed evidence, provenance, reviewer, and date.
  No import, typed model, URL, photo, candidate match, simulation, or software test
  self-verifies hardware.
- Inventory/reconciliation has robot authority `NONE` and cannot pass commissioning
  gates or widen Hardware Profile/driver/control authority.

# 2026-08-29 — Real hardware workbook intake boundary

- Accept `HW-001` through `HW-031` as evidence-supported working inventory without
  automatically reviewing, verifying, keeping, binding, commissioning, or approving
  any item. Keep `HW-032` antenna and `HW-033` XL4015E seller-reference rows outside
  purchased inventory until purchase/receipt is explicitly confirmed.
- Treat the workbook's Camera Pin Map, GPIO Allocation, Full Wiring Map, and Firmware
  Pin Defines as provisional engineering drafts only. Seller wording cannot override
  the repository evidence policy or freeze physical wiring/firmware pins.
- Preserve actual-versus-candidate mismatches: VL53L0X-family does not silently satisfy
  VL53L1X, and WS2812/WS2811 breakouts do not silently satisfy the belly-matrix
  candidate. Keep the 5 V / 3 A board electrically blocked until its terminals,
  range, polarity, isolation, protection, and safe-current behavior are verified.
- At the 2026-08-29 workbook-intake snapshot, receipt evidence for `HW-017` confirmed
  purchase only. The later observed physical presence is recorded in the superseding
  decision above. Inventory evidence still cannot grant robot authority or pass any
  physical commissioning gate.

# 2026-08-30 — First real bench evidence-closure boundary

- Keep first-bench reporting derived from the existing inventory/reconciliation model
  and existing WHAT I NEED FROM YOU surface; add no parallel workflow or authority.
- Current evidence permits unpowered identification and measurement only. A received
  item is not power-ready merely because family voltage/interface text exists.
- Require item-specific identity, input/output, logic-level, connector and protection
  review before considering isolated active-module tests. Such a test does not satisfy
  integrated first-power or commissioning gates.
- This session mistakenly recorded `HW-002` as received; the superseding decision
  above corrects it to NOT_ARRIVED/UNVERIFIED. Preserve the valid safety consequences:
  keep `HW-010` unpowered/disconnected and keep HW-002 blocked until arrival and
  board-specific evidence review,
  production GPIO/harness unfrozen, STM32/motion/CAN blocked, Phase2B2 waiting, and
  physical commissioning at zero passes.

# 2026-08-30 — Vendor toolchain and physical-target integration boundary

- Keep vendor SDKs/toolchains outside Zi-E and detect them through a read-only doctor.
  Use the existing setup plus one fixed firmware workflow; do not create another setup
  system or expose target commands through the HUD.
- Keep ESP32 and STM32 production composition `BOARD_BINDING_DISABLED` until an
  explicitly reviewed repository board profile exists. Never add fake GPIO, clock,
  timer, electrical or CAN values to obtain a successful build.
- Require explicit reviewed board profile plus exact COM port or ST-LINK serial for
  flash/program workflows. Never select the first discovered device.
- Preserve the semantic App/HostRuntime boundary and Phase2A/2B1. Real-target config
  cannot create availability or authority; Phase2B2 remains waiting and no physical CAN
  transmit binding exists.
- Adopt Bench 0 through Bench 7 progression. Only Bench 0 is executable now; USB logic
  power and robot-wide physical power remain separate gates.
# ESP32 Presence Runtime implementation decisions — 2026-08-30

- Generic ESP32-S3 smoke builds compile only with every physical binding, production
  run, TWAI and physical authority disabled; no placeholder pins exist.
- Structured control is capped at 16 KiB and separate camera transfer at 2 MiB.
- Host presence link—not Internet—selects online versus offline Face mode.
- Host Face Library metadata is bounded to 2,048 packs; device-cache planning is eight
  validated identities and performs no deployment.
- Vision is an independent provider modality; wake remains local ESP32 capability.
- Control Center stays 0.04 and derives that version from the authenticated backend.

# Target Architecture Freeze Candidate V1 — 2026-08-30

- Freeze-candidate ownership is HostRuntime brain/coordinator, ESP32-S3 presence and
  authenticated semantic bridge, and STM32 physical safety/motion authority.
- XiaoZhi at pinned SHA `374a5ccf95c2ed513dbad9ca204adbac75062dce` is an MIT
  engineering donor only. Zi-E stays cloud-, provider-, donor-, and board-replaceable.
- Prefer official maintained ESP-IDF/Espressif/LVGL components over copying donor
  wrappers; use donor glue only after a file-level license/risk review.
- Zi-E Face Engine is semantic and locally animated. Online Host intent forbids random
  full-face switching; offline contextual personality never creates motion.
- Face Packs are bounded data with hash/license/provenance and no executable content.
- Critical local voice grammar is only STOP/FREEZE/EMERGENCY_STOP; recognition grants
  no authority and physical kill/E-stop remains higher.
- No pins, board revisions, CAN values, electrical facts, memory partitions, or
  physical timings were frozen by these decisions.

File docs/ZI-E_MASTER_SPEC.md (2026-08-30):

# ZI-E Master Specification — 2026-08-23

## 1. Source-of-truth rule
ZI-E is an original desktop AI companion robot. This file describes the current approved architecture. Legacy WALL-E files are historical reference only and may contain contradictions, pin conflicts, or obsolete assumptions. Current CAD, current-state docs, verified component datasheets, tests, and approved decision logs override legacy material.

## 2. Design intent
- Desktop-sized, compact, premium/cute/futuristic robot; not a WALL-E/BMO copy.
- One landscape digital face screen; hidden camera brow; clean exterior.
- Structural chassis carries loads; cosmetic shell is removable/protective.
- Buildable, serviceable, modular, testable, and upgradeable.
- Exact final external dimensions remain subordinate to real component packaging, swept volumes, mass/COM, cable routing, and testing.

## 3. High-level intelligence architecture
`Laptop / future phone AI brain ↔ Wi-Fi ↔ ESP32-S3 multimedia controller ↔ classical CAN ↔ STM32 safety/motion controller`.

The AI layer sends high-level intents only. It never receives unrestricted raw actuator authority. The local safety/motion controller enforces limits, interlocks, heartbeats/timeouts, sensor plausibility, current budgets, and safe-stop behavior.

## 4. Main electronics
### Multimedia controller
- ESP32-S3-WROOM-1-N16R8.
- Responsibilities: display/UI/face animation, OV5640 camera, touch, audio path, Wi-Fi/BLE, laptop/phone communications, high-level robot state.
- 16 MB flash / 8 MB PSRAM class.

These are design-candidate requirements, not received-board evidence. HW-002 has not
arrived, so its actual module, memory, camera, revision, pins, and power behavior
remain unverified. The separate HW678 spare's verified 16 MB/8 MB configuration does
not prove HW-002.

### Safety / motion controller
- STM32G0B1RET6.
- Responsibilities: deterministic motion, safety supervision, sensor fusion, actuators, limits, current/fault supervision, cliff/collision handling, heartbeat/command lease, safe-state transitions.

### Main inter-controller link
- Classical CAN/TWAI. CAN-FD is not required for the ESP32-S3 link.

### IMU
- LSM6DSOX primary candidate; BMI270 backup.
- Mounted to rigid chassis near robot center, isolated from avoidable vibration/magnetic interference.

## 5. Face / camera / audio
### Display
Primary candidate: 3.5-inch IPS TFT, 320×480 native (used landscape as 480×320), ILI9488, capacitive touch, SPI/parallel capable.
- Final mode starts with SPI to conserve GPIO and simplify integration.
- Before purchasing/final PCB freeze: exact FPC pinout and exact capacitive-touch controller must be confirmed.
- Backup A: documented EastRising/BuyDisplay 3.5-inch IPS touch panel in similar envelope.
- Backup B: equivalent 3.5-inch IPS touch panel with documented pinout and replaceable adapter frame.

### Camera
- OV5640 5 MP autofocus primary; OV2640 budget fallback.
- Camera sits top-center in structural sensor brow.
- Aesthetic smoked cover is allowed only if low-light/vision testing remains acceptable.

### Dedicated laser rangefinder
- Primary: VL53L1X single-point Time-of-Flight sensor, invisible 940 nm Class 1 laser, up to 4 m / 50 Hz.
- Prototype CAD reserves a 25.5 × 17.5 × 4.6 mm carrier; final head sensor PCB may use the 4.9 × 2.5 × 1.56 mm bare package.
- Located in the modular head sensor brow beside the centered OV5640; it does not replace the lower STM32 cliff/proximity safety sensors.
- Primary role: requested distance measurement, camera/object distance assistance, approach measurement and vision calibration.
- The sensor is single-point: camera/rangefinder extrinsic alignment must be calibrated and software must expose the actual ranging point.
- Optical cover must be qualified around 940 nm, with minimized air gap/tilt and offset/crosstalk calibration after assembly. Arbitrary smoked plastic is not accepted without measurement.
- Backup A: Benewake TF-Luna 0.2–8 m / up to 250 Hz if field requirements exceed 4 m or 50 Hz.
- Backup B: TFmini-S class only if a real longer-range requirement appears.
- Detailed rules: `docs/LASER_RANGEFINDER_SPEC.md`.

### Microphones
- 2 matched I2S MEMS microphones in the head brow, symmetric around camera.
- Current candidate: PUI DMM-4026-B-I2S-R; TDK T5848 class is a backup.
- Do not expand to four microphones unless A/B acoustic testing proves a real benefit.

### Speaker
- One full-range speaker in isolated lower-front/slightly-side acoustic chamber.
- Current candidate class: PUI AS04004PO-R (~40 mm, 4 Ω / 2 W class); smaller AS02404PO fallback if CAD space requires.
- MAX98357A I2S class-D amplifier.
- Speaker stays out of head to minimize head mass and microphone/camera vibration.

## 6. Head mechanics
The head has three controlled DOF/modes: Pan, Tilt, and vertical retract.

### Pan
- SC09 smart servo primary, short 1:1 timing belt, external bearing-supported pan ring with hollow cable center.
- Limited rotation, roughly ±120° design envelope; no continuous 360°/slip ring.
- ST3036 class backup if jitter/backlash is unacceptable.

### Tilt
- SC09 primary with about 2:1 belt reduction; dual external bearings carry head load.
- Pivot placed close to measured head COM.
- ST3036 backup for precision; HL2915 backup for higher torque.
- Small counterbalance spring may be added after measured head mass/COM.

### Lift
- N20 12 V ~200 RPM encoder gearmotor + T5×2 lead screw.
- One precision rail with two spaced carriage blocks plus secondary anti-rotation guide.
- Top and bottom sensors, encoder, mechanical hard stops, current-based jam detection, and manual screw recovery.
- Counterbalance spring target is set only after actual head weighing; do not assume lead-screw self-locking.

### Head operating states
- Active: head raised, Pan/Tilt enabled, camera/display operational.
- Sleep: head lowered enough to hide neck while most face remains visible.
- Protected Shutdown: Pan centers, Tilt moves to dock angle, positions are confirmed, then head retracts deeply/flush; loads rest on three structural supports with compliant pads; no structural latch.

## 7. Body / chassis / service architecture
- Central Head Bay is a strict keep-out volume.
- Left/right structural shoulder towers form a portal around Head Bay.
- Rear/lower bridge and lower chassis carry loads.
- Battery is low and central.
- Rear service shell is sculpted, removable, cosmetic/protective, with no essential wiring attached to it.
- Precision structures remain aligned when the shell is removed.
- Immediate rear access targets: master disconnect/fuse, power board, controller/connectors, debug/service interfaces.
- Internal rails/adapter plates should allow future boards/actuators without re-cutting the entire chassis.

## 8. Arms
Current chain per arm:
`2-DOF bearing-supported Shoulder → proximal belt-driven Elbow → one-stage keyed Telescopic Forearm → limited bearing-supported Forearm Roll → dual-bearing Wrist Pitch → Quick-Swap → Tool`.

### Shoulder
- 2× STS3215-C018 12 V smart servos per arm, motors close to body.
- Gravity-loaded axis may use ~1.3–1.5:1 reduction; second axis may stay near 1:1.
- External bearings/axles carry loads; servo does not act as structural bearing.
- Final status remains conditional on measured/dummy-arm load and thermal tests.

### Elbow
- HL2915-C001 12 V primary, mounted proximally in upper arm, short toothed belt about 2:1 to a dual-bearing elbow axle.
- STS3215 fallback if physical torque/thermal margin is inadequate.

### Telescopic forearm
- N20 12 V encoder gearmotor + T5×2 lead screw + POM nut initially.
- Keyed/non-round sliding geometry and two spaced guide/wear regions carry lateral loads.
- Add thrust bearing so lead-screw axial load does not enter gearbox.
- Retract and extend sensors plus physical stops; current+encoder jam logic.
- Stroke is not frozen until full arm packaging/stability analysis.

### Forearm roll
- SC09 primary, short reduction and hollow bearing-supported output shaft.
- Rotation is limited, not continuous, to protect cables.
- Use optical/mechanical index if needed; avoid Hall reference near magnetic tool.
- ST3036 class backup if load/precision tests fail.

### Wrist pitch
- SC09 primary with about 2:1 reduction and dual external bearings.
- Designed around ~150 g tool class initially; heavier tools trigger stronger backup such as ST3036/HL2915 and/or lower allowed payload.

### Arm safety/stow
- Sequential stow: tool safe → wrist → roll → telescope retract → elbow → shoulders/body dock.
- Each stage confirms previous state; no force-through on failed confirmation.
- Structural docking pockets and compliant pads carry stowed arm loads.
- Collision model includes head safety volume, body, left/right links, and tool envelopes.
- Payload/speed/base-motion limits change with extension and tool metadata.

## 9. Default gripper tool
- 2-finger adaptive underactuated gripper, one SC09 actuator.
- Tendon/differential mechanism, two rigid phalanges per finger, return torsion springs.
- Spring-open/fail-release behavior on power or tendon failure.
- Replaceable soft TPU/silicone pads, rounded precision/V-groove tips.
- Series-elastic tendon element limits pinch force; servo feedback is not treated as a calibrated force sensor.
- Future tactile sensors are reserved but not mandatory for V1.

## 10. Magnetic pickup tool
- Dedicated quick-swap tool rather than a strong permanent palm magnet.
- P20/15 12 V electromagnet class is current prototype candidate.
- Local MOSFET drive, temperature sensing, contact/part detection, compliant/floating mount, protective ring.
- Marketing holding-force numbers are not treated as payload ratings; real pull-force versus material/thickness/air-gap/temperature must be bench measured.
- Default is fail-release electromagnet for V1; electro-permanent magnet remains a future alternative if requirements change.

## 11. Quick-swap interface
- 3-point tapered/self-centering seating.
- Asymmetric key.
- 3-lug short-twist bayonet primary lock.
- Spring safety collar; manual release requires pull + twist.
- Structural interface carries load; contacts carry no structural load.
- 8 contacts: 2× VTOOL+, 2× GND, RS485_A, RS485_B, passive TOOL_ID, AUX.
- Independent left/right wrist RS-485 links.
- Tool power remains off until lock confirmed and tool ID is plausible.
- Opening collar cuts tool power before rotation/unmating.
- Each tool has a small local MCU (STM32C011-class) and independent transceiver/driver electronics as required.

## 11B. Hidden Belly Light Matrix (BLM)
- Fixed-torso low-resolution RGB information/ambient-light surface, hidden when off.
- Prototype electronics: IS31FL3741 13×9 / 117 RGB pixel class; final custom PCB may be wider within the reserved CAD keepout.
- Current CAD v0.3 reserves an 80 × 54 × 12 mm electronics/optical keepout and a flush ~74 × 46 mm optical insert.
- Optical insert is secret-until-lit PC/PMMA with body-matched finish/coating; an opaque normal shell cannot provide the effect.
- Internal black baffle/light well suppresses crosstalk and seam glow.
- Controlled by ESP32-S3 on a non-safety bus/power path. The matrix may fail dark without affecting safety.
- Hardware enable/load switch and global current/brightness cap are mandatory.
- Intended information includes clock, timer, battery, charging, tool state, warnings, directional cues, AI state, audio visualization and ambient effects.
- Safety/warning presentation has priority over cosmetic AI animation.
- Final optical material, transmission, diffuser spacing, brightness and thermal limit require bench coupon testing before custom PCB/panel purchase.

## 12. Mobility
- Exactly 2 independently powered fixed wheels, differential drive. Not four powered wheels, not mecanum/omni drive.
- Hidden passive ball caster provides the third normal support point.
- Front/rear passive anti-tip skids catch excessive tipping.
- Wheels manually fold/tuck for Protected Shutdown; robot then rests on four fixed rubber feet.
- Wheel module: 25 mm-class encoded gearmotor → short timing belt → independent axle on two bearings → replaceable soft tread wheel.
- Current motor candidate: 25SG-370CA-78-EN 12 V ~108 RPM no-load class, with encoder.
- Current driver: one DRV8876 per wheel with current sensing/regulation.
- Drive is disabled unless both wheel deployed locks are independently confirmed.
- Final wheel diameter/tread/ratio remain physical test items; ~60–65 mm is only the present class/envelope.

## 13. Desk-edge and collision safety
### Cliff sensing
- Current architecture: 4× downward VL53L4CD, one near each lower corner.
- These are local STM32 safety inputs, not AI-only perception.
- Invalid/stale critical cliff reading causes stop.
- Mandatory physical tests include white, matte black, glossy black, wood, metal, mirror/reflective surfaces, clear glass, tablecloth/edge overhang, sunlight/darkness, dirty/blocked/unplugged sensors, rounded edges, and multiple payload configurations.
- If optical common-cause blind spots remain, add independent mechanical cliff feelers rather than simply adding more of the same optical technology.

### Horizontal collision
- Current design reserves four lower-body horizontal VL53L4CD-class proximity sensors; this is conditional on cost/space.
- Cost fallback: two horizontal ToF plus bumper ring/camera, but downward cliff sensing is not reduced for cost.

### Physical bumper
- Thin compliant lower bumper with four independent microswitches, current candidate Omron D2F-L class; sealed D2HW-class backup if needed.
- Bumper hit is handled locally by STM32.

## 14. Battery, protection, charging, and rails
### Battery
- 3S2P 18650 Li-ion pack, Molicel M35A candidate.
- Nominal pack class ~10.8 V, full 12.6 V, ~7 Ah / ~75 Wh class.
- Low-central longitudinal battery cassette with structural rails, hard stop, positive rear latch, keyed connection, elastomer anti-rattle pads, and service/removal access.
- No direct hand-soldering to cells; final pack should be professionally/appropriately assembled with proper interconnects and protection.

### Protection
- BQ7791500-class 3–5S protection/balancing family is current direction; exact sense resistor, MOSFETs, fuse, and thermistor implementation freeze only after measured current profile and pack tests.
- Main fuse/service disconnect remain mandatory.

### Charging V1
- External certified 12.6 V CC/CV charger, around 2 A class.
- Charging connected disables drive/arms.
- Integrated USB-C PD charging remains a later polished-revision option.

### Power rails
- Raw 3S rail for suitable 12 V-class motors/actuators, under branch protection/current budgets.
- AP62300-class buck converters for general 5 V / 3.3 V rails where suitable.
- Independent TPS62162-class 3.3 V safety rail for STM32/critical sensors.
- 6 V arm/head servo rails sized to real grouped stall/thermal behavior; current arm design uses a higher-current ~6 A-class buck per arm plus upstream current limiting/eFuse.
- TPS25947-class eFuse/current-limited branches for arms/tools where applicable.
- Motion Kill cuts actuator enables/rail authority without killing safety diagnostics.

## 15. Physical controls and safety states
- Physical Power control.
- Hardware Motion Kill.
- Hardware Privacy control intended to power-disable camera/microphones where practical.
- States: OFF → BOOT/SELF-TEST → SAFE_IDLE → ACTIVE → MANIPULATION → SLEEP → PROTECTED_SHUTDOWN, plus CHARGING/SERVICE/FAULT.
- Transitions are gated by actual confirmed state, not command assumptions.
- Wi-Fi/laptop loss, stale command lease, impossible sensor state, overcurrent, jam, critical cliff fault, or safety-controller fault triggers locally defined degraded/safe behavior.

## 16. Software / AI behavior boundary
- AI: vision, speech, language model, memory/database, behavior selection, high-level task planning.
- Local controller: deterministic motion and safety.
- Early “learning” means stored memory/retrieval/adaptation, not autonomous continuous model retraining on the robot.
- Local ring-buffer/flight-recorder fault logging is required.
- Updates and communications must eventually use authenticated/encrypted channels with rollback-safe update architecture.

### Commissioning / execution semantics added from open-source failure review
- First power-up uses a low-current commissioning state: scan actuator IDs/model/baud, verify voltage class, direction, physical indexing, zero/range and feedback one joint at a time. No autonomous animation before this passes.
- A motion request has explicit states such as RECEIVED / ACCEPTED / ARMED / EXECUTING / COMPLETED / REJECTED / FAULTED. Receipt is never treated as proof of motion.
- One command arbiter owns each moving subsystem; AI, web UI, teleoperation and scripted behavior cannot fight over raw setpoints.
- Servo/head/arm cable topology avoids unnecessary downstream dependence on pass-through connectors; left/right/head remain separately isolatable fault domains.
- Dynamic payload/tool mass and COM feed stability and torque limits.
- Dynamic collision zones expand with speed, arm extension, tool length, payload and head height; stale critical range data means stop.

## 17. Thermal / EMI / RF / wiring
- Separate high-current/noisy power routes from sensitive data/audio/RF routes.
- Keep RF antenna area in an upper/rear nonmetallic region away from battery/large metal structures.
- Fixed chassis-mounted motor drivers and power electronics; dynamic wiring only where motion requires it.
- Controlled flex loops for Tilt, Pan center, vertical lift, arm telescope, and wheel folding.
- Strain relief and minimum bend radius are CAD keep-outs, not afterthoughts.
- Passive thermal path must work even in Protected Shutdown; add fans only if measured thermal tests prove necessary.

## 18. CAD status
Current project/CAD release is **v0.3** and is in `mechanical/cad/current/`.
- Parametric source: `src/zie_cad.py`.
- STEP/STL/glTF exports provided.
- Active, Sleep, Shutdown and Cutaway states included.
- Current automated validation snapshot (CAD v0.3): 39 checks total; 38 pass; one case (two arms each carrying 250 g forward) is intentionally restricted for normal driving because static stability margin drops below target.
- Current mass estimate: ~2.44 kg, low/medium confidence until real parts and printed masses are measured.
- Current active envelope is about 248 mm wide × 174 mm depth × 282 mm tall in the modeled state; these are CAD-state outputs, not immutable product dimensions.

## 19. Engineering method / mandatory loops
Every significant change is reviewed through: requirements → research → alternatives → FMEA → common-cause → tolerance/manufacturing → abuse/human error → test plan → integration → change-impact → lifecycle/wear → red-team → approval/redesign.

Additional mandatory checks include memory/inventory loop, **Open-Source Harvest Loop (including issue trackers/troubleshooting)**, interface/dependency loop, worst-combination loop, recovery loop, stale-data/timeouts, boot ambiguity, sensor blind spots/common power, STPA/fault-tree thinking for catastrophic outcomes, graceful degradation, calibration drift, logging/observability, latency, mass/space/energy/cost budgets, privacy/cybersecurity, supply-chain/obsolescence, repair/end-of-life, and an experiment ladder from simulation to controlled physical integration.

## 20. Unresolved / freeze-gate items
Do not call these production-frozen until physically verified:
- Exact selected display FPC/pinout/touch-controller.
- Measured head mass/COM and final Tilt/Lift spring values.
- Dummy-arm/full-arm torque, backlash, thermal, and endurance results.
- Exact telescope stroke and cable flex life.
- Wheel tire diameter/material, traction and scrub behavior.
- Cliff performance on glass/black/mirror/edge cases.
- Electromagnet real pull force and temperature.
- Final BMS shunt/MOSFET/fuse sizing from measured current profiles.
- Acoustic chamber tuning and microphone AEC/beamforming performance.
- Cable bend radii and service life.
- Final external shell dimensions/industrial-design surfaces after physical package validation.

## 21. Prototype experiment ladder
1. CAD geometry/swept-volume/collision checks.
2. Cheap dummy geometry and weighted mechanical rigs.
3. Powered bench rigs for each mechanism.
4. Endurance cycling.
5. Jam/power-loss/misalignment/fault injection.
6. Subsystem integration.
7. Full robot tethered/contained tests.
8. Normal prototype operation after safety gates pass.

Never use uncontrolled home tests for deliberate lithium thermal runaway or similarly hazardous fault creation.

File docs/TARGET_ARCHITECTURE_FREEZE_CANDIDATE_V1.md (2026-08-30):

# Target Architecture Freeze Candidate V1

Status: `FREEZE_CANDIDATE`; software responsibility boundaries only. Hardware
bindings, physical constants, first power, and Phase2B2 are not frozen.

## Ownership and authority

`Zi-E Brain / HostRuntime -> authenticated semantic transport -> ESP32-S3 Presence
Runtime -> bounded semantic controller link -> STM32 Safety / Motion Authority`.

- HostRuntime coordinates Robot API, services, profiles, identity, providers, and
  copied readiness. It has no physical actuator authority.
- ESP32 owns network edge, audio, camera, display/face, local wake/status behavior,
  and a semantic bridge. It cannot override STM32 or invent offline motion.
- STM32 alone owns physical safety enforcement, trajectory/actuator representation,
  hard limits, and the right to reject or stop motion.
- Provider Manager owns independent LLM/STT/TTS/Vision chains. Hermes is an LLM
  gateway, not a robot authority or an implied STT/TTS/Vision implementation.
- XiaoZhi is a pinned engineering donor, never Zi-E's brain, runtime dependency, or
  authority model.

The only motion path is `HostRuntime -> ESP32 semantic bridge -> STM32 -> hardware`.
No public boundary exposes GPIO, PWM, registers, timers, raw servo/motor/current
units, raw CAN transmit, or safety bypass. AI, providers, MCP, plugins, face, camera,
audio, and HUD cannot grant authority.

Every command-capable flow preserves `session_id`, `generation_id`, and `command_id`.
Restarts, reconnects, peer reset, generation replacement, timeout, malformed input,
or link loss retire authority; old authority never reactivates. `ACCEPTED` is not
`EXECUTED` or `COMPLETED`. STOP is idempotent and higher priority than ordinary
motion; the physical kill/E-stop remains higher still.

## Target boundaries

- Host/ESP32: [HOST_ESP32_INTERFACE_V1.md](HOST_ESP32_INTERFACE_V1.md).
- ESP32/STM32: [ESP32_STM32_SEMANTIC_INTERFACE_V1.md](ESP32_STM32_SEMANTIC_INTERFACE_V1.md),
  built on existing Phase2A and Phase2B1 session/lifecycle foundations.
- Providers: [PROVIDER_INTERFACE_V1.md](PROVIDER_INTERFACE_V1.md).
- Presence: [FACE_ENGINE_INTERFACE_V1.md](FACE_ENGINE_INTERFACE_V1.md).
- Offline critical voice: [LOCAL_SAFETY_VOICE_CONTRACT_V1.md](LOCAL_SAFETY_VOICE_CONTRACT_V1.md).
- Existing authority, identity, profile, package, extension, commissioning, and App
  boundaries remain authoritative in `SOFTWARE_ARCHITECTURE_FREEZE_CANDIDATE.md`.

## Explicitly unfrozen

All GPIO/pins, board/camera/touch identity, CAN bitrate/IDs/packing/fragmentation,
heartbeat/deadline/queue values, transceiver/termination/wiring, electrical ratings,
motor/servo/encoder constants, flash partitions, and physical timings remain
evidence-gated. `HW-002` remains ordered and unverified. Phase2B2 remains
`WAITING_FOR_VERIFIED_INPUTS`; first power and physical commissioning are not done.

## Adversarial closure

The candidate was challenged for AI-to-PWM, MCP-to-motor, ESP32-over-STM32,
Host-to-STM32 bypass, stale-session replay, ACCEPTED-as-COMPLETED, offline-face motion,
executable/oversized Face Packs, arbitrary OTA URL, seller-pin promotion, donor-board
inventory promotion, Hermes authority, cross-modality fallback, free-form safety
voice, and online random faces. Each is denied by the boundaries above plus bounded
pack/face/safety tests. Remaining wire authentication, archive parsing/storage budget,
physical timing, and controller-link fault injection stay open gates—not implied proof.

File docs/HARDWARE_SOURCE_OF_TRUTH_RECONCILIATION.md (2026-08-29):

# Hardware Source-of-Truth Reconciliation — Prototype P1

## Control Center 0.04 decision reports

The primary candidate table is a fixed design-reference catalog for Required Hardware
and WHAT I NEED FROM YOU reports. It is never converted into purchased inventory.
Exact normalization can suggest `MATCH_REVIEW_REQUIRED`; similarity can suggest only
`POSSIBLE_MATCH`; explicit review is required for `MATCHED`, decisions, or verification.
With empty inventory, required classes remain missing and request actual labels, photos,
datasheets, receipt state, and relevant measurements—never invented values.

Status: canonical repository reconciliation as of 2026-08-28. This is a design
inventory, not proof of purchase, receipt, fit, electrical suitability, or
commissioning. The future purchased-parts sheet, label photos, datasheets, and measured
worksheets supersede candidate assumptions for the received article.

## Status vocabulary

- `VERIFIED`: physically identified/measured on the received article. No component in
  this matrix currently qualifies.
- `DOCUMENTED_NOT_PHYSICALLY_VERIFIED`: repository decision/candidate supported by a
  cited source, but not reconciled to received hardware.
- `VERIFY_ON_ARRIVAL`: exact variant, interface, envelope, rating, or behavior must be
  checked before use/CAD freeze.
- `REPLACE`: repository decision rejects the item. None is newly asserted here.
- `UNDECIDED`: selection or implementation is still open.
- `WAITING_FOR_VERIFIED_INPUTS`: an architecture placeholder exists, but the listed
  physical evidence is required before parameters or implementation may be frozen.

`Power` contains only repository-documented class information. `TBD` is intentional.
Slots and drivers are semantic mappings; they confer no raw hardware authority.

## Canonical component/module matrix

| Canonical component/module | Role; owner | Documented interface / power | Hardware Profile slot; driver/extension class | CAD dependency; safety | Status | Evidence; physical verification required |
|---|---|---|---|---|---|---|
| 3.5-inch 480x320 IPS touch display, ILI9488 candidate | Face/display; ESP32-S3 | Exact FPC/touch interface TBD; power TBD | `display.face`; ESP32 display embedded module | Head bezel, thickness, FPC route; non-safety | `VERIFY_ON_ARRIVAL` | Component matrix + v0.3 envelope; exact panel/IC, active area, thickness, holes/adhesive, connector/FPC orientation, voltage/current |
| Adafruit IS31FL3741 13x9 prototype matrix | Belly light prototype; ESP32-S3 | Driver class documented; exact wiring/power TBD | `rgb.belly`; ESP32 presentation embedded module | 80x54x12 reserved keepout; cosmetic, must fail dark | `VERIFY_ON_ARRIVAL` | Component matrix/Belly spec; exact PCB, connector, current/thermal/optics |
| Secret-until-lit belly insert/baffle | Optical/mechanical; passive | PC/PMMA candidate; no electrical interface | `presentation.belly_optics`; data/mechanical | Torso window/baffle; non-safety but thermal/fault containment relevant | `VERIFY_ON_ARRIVAL` | CAD/Belly spec; material, thickness, transmission, light bleed, temperature, fit |
| OV5640 5 MP autofocus camera candidate | Vision; ESP32-S3 | Exact module/FPC interface and power TBD | `camera.head`; ESP32 camera embedded module | Sensor brow, FPC loop/window; non-safety | `VERIFY_ON_ARRIVAL` | Component matrix/CAD envelope; exact module/revision, lens, board size, connector, focus/clearance/FOV |
| VL53L1X head rangefinder | Non-safety forward range; ESP32-S3 | Sensor interface documented elsewhere as I2C; power/pins TBD | `range.head`; ESP32 range embedded module | IR window, camera alignment, carrier; non-safety | `VERIFY_ON_ARRIVAL` | Laser spec/CAD; exact carrier vs bare sensor, window transmission/crosstalk, FOV/alignment, known-distance behavior |
| ESP32-S3-WROOM-1-N16R8 candidate | Multimedia/presence/semantic host; ESP32-S3 | TWAI and multimedia interfaces; board/carrier/power TBD | `controller.multimedia`; protected host composition, not plugin raw access | ESP32 zone, RF/USB/service access; authority boundary relevant | `VERIFY_ON_ARRIVAL` | Component matrix/vendor-derived envelope; exact module/board/revision, dimensions, antenna keepout, USB/boot, voltage/current |
| STM32G0B1RET6 candidate/custom carrier reservation | Local safety/motion; STM32 | FDCAN-capable MCU; carrier/pins/power TBD | `controller.safety`; built-in protected safety module | STM32 zone, debug/service, actuator gating; safety-critical | `VERIFY_ON_ARRIVAL` | Component matrix/CAD carrier reservation; exact MCU/board/revision, clocks, debug, dimensions, pins, voltage/current |
| ESP32–STM32 Classical CAN/TWAI link | Bounded semantic link; ESP32/STM32 | Classical CAN only; bitrate/IDs/framing/transceiver TBD | `link.controller`; protected controller-link service | Harness/topology/termination; safety-critical liveness | `WAITING_FOR_VERIFIED_INPUTS` | Phase 2B2 analysis; all inputs in `PHASE2B2_INPUT_GATE.md` |
| LSM6DSOX IMU candidate | Inertial sensing; STM32 for safety-relevant state unless later approved otherwise | Interface/power TBD | `imu.body`; protected sensor driver if used for safety | Board placement/alignment; safety relevance depends on use | `VERIFY_ON_ARRIVAL` | Component matrix; exact breakout/variant, interface, orientation, noise, dimensions, voltage/current |
| VL53L4CD downward cliff sensors, four planned | Local cliff sensing; STM32 | Interface/power/addressing TBD | `cliff.downward.*`; built-in protected safety sensor driver | Lower windows/angles/ground clearance; safety-critical | `VERIFY_ON_ARRIVAL` | Component matrix; count/variant, FOV, addresses, window, surface/sunlight/occlusion behavior |
| VL53L4CD horizontal proximity, four planned/conditional | Local proximity; STM32 | Interface/power/addressing TBD | `proximity.horizontal.*`; protected sensor driver if safety-gating | Bumper/lower shell windows; safety-relevant | `UNDECIDED` | Component matrix permits reduction to two; Product Owner decision plus physical coverage testing required |
| D2F-L-class bumper switches, four planned | Contact collision input; STM32 | Discrete interface/power TBD | `bumper.contact.*`; built-in protected safety input | Bumper segments, preload/travel; safety-critical | `VERIFY_ON_ARRIVAL` | Component matrix; exact switch/lever, force/travel, mounting, wiring, debounce, fault response |
| 25SG-370CA-78-EN-class 12 V encoded wheel motors | Differential drive; STM32 | Encoded motor; exact encoder/driver wiring TBD; 12 V class documented | `drive.left/right`; built-in protected drive driver | Wheel pods, shaft/mount, belt/fairing; safety-critical | `VERIFY_ON_ARRIVAL` | Component matrix/CAD envelope; exact label/ratio, shaft, holes, encoder, no-load/load current, speed, thermal |
| DRV8876 protected H-bridge class, two | Wheel power stages; STM32 | Exact carrier/interface TBD; sizing TBD | `drive.power.left/right`; built-in protected drive driver | Power board/heatsinking; safety-critical | `VERIFY_ON_ARRIVAL` | Component matrix; exact part/carrier, current/thermal/protection, fault behavior |
| 64 mm-class wheel/tire and folding pod | Traction/support; passive + STM32 drive | Mechanical; no final interface | `drive.wheel.*`; physical drive assembly | Diameter/tread/fold lock/support polygon; safety-critical | `VERIFY_ON_ARRIVAL` | v0.3 CAD parameter/model only; measured diameter, width, traction, braking, runout, lock loads |
| POM ball-caster cartridge candidate | Passive third contact | Mechanical | `support.caster`; passive | Base support/COM; safety-relevant stability | `UNDECIDED` | Component matrix/CAD 25.4 mm model; exact unit, height, friction, mounting, surface behavior |
| Molicel M35A-class 18650 cells, 3S2P architecture | Energy storage; passive/protected power | 3S2P class; exact pack implementation TBD | `battery.main`; built-in protected power service | Battery cassette/COM/fire containment; safety-critical | `VERIFY_ON_ARRIVAL` | Component matrix/CAD; cell provenance/labels, lot, dimensions/mass, pack construction, voltage/internal behavior |
| BQ7791500-class pack protection | BMS/protection; protected power/STM32 monitoring as designed | Exact variant/schema TBD | `power.pack_protection`; built-in protected safety power module | Power board/thermal/service; safety-critical | `UNDECIDED` | Component matrix marks implementation conditional; exact variant, schematic, thresholds, shunt/FET/fuse evidence |
| Certified external 12.6 V ~2 A CC/CV charger class | V1 charging; external/passive | 12.6 V class documented; connector TBD | `power.charger_external`; no plugin control | Charge connector/service; safety-critical | `VERIFY_ON_ARRIVAL` | Component matrix; certification/provenance, polarity, connector, measured output, pack compatibility |
| AP62300-class general buck regulators | Logic/multimedia rails; power board | Exact rails/sizing TBD | `power.logic_rail.*`; protected power driver | Power board/thermal; safety-relevant isolation | `UNDECIDED` | Component matrix only class-level; exact part, rail requirements, load/inrush/thermal measurements |
| TPS62162-class safety 3.3 V supply | Safety logic rail; STM32/protected power | Exact implementation TBD | `power.safety_3v3`; built-in protected power driver | Safety board/power separation; safety-critical | `UNDECIDED` | Component matrix class-level; exact design, load/transient/thermal/fault isolation |
| TPS25947/eFuse-class arm/head protection | Branch current limiting; STM32/protected power | Exact implementation/limits TBD | `power.actuator_branch.*`; built-in protected power driver | Power board/harness; safety-critical | `UNDECIDED` | Component matrix class-level; exact part, limits, fault response, measured branch loads |
| Feetech STS3215-C018 shoulder servos, two per arm planned | Shoulder motion; STM32 | Servo bus/voltage/IDs not frozen | `arm.*.shoulder.*`; protected actuator driver | Shoulder towers/yokes; safety-critical motion | `VERIFY_ON_ARRIVAL` | Component matrix/CAD envelope; exact model/voltage, identity, bus/baud/ID, horn/spline, current/thermal/backlash |
| Feetech HL-2915-C001 elbow servo + ~2:1 candidate reduction | Elbow motion; STM32 | Servo bus/voltage not frozen | `arm.*.elbow`; protected actuator driver | Arm housing/belt geometry; safety-critical motion | `VERIFY_ON_ARRIVAL` | Component matrix/CAD estimate; exact servo, ratio/pulleys, current/thermal/load/backlash |
| Waveshare SC09-class servos | Forearm roll, wrist pitch, pan, tilt, gripper candidates; STM32 | Interface/voltage/IDs not frozen | corresponding `arm.*`, `head.pan/tilt`, `gripper.*`; protected actuator drivers | Multiple mechanism envelopes; safety-critical motion | `VERIFY_ON_ARRIVAL` | Component matrix/CAD envelope; exact count/model, voltage, identity, bus, spline, range, current/thermal/jitter |
| N20 encoder motor + T5x2 lead mechanism | Telescope and head lift candidates; STM32 | Exact motor/encoder/driver/end sensing TBD | `arm.*.telescope`, `head.lift`; protected actuator drivers | Rail/lead screw/cable loop; safety-critical motion | `VERIFY_ON_ARRIVAL` | Component matrix/CAD model; exact motor/gear ratio, screw/nut, travel, current, end sensors, backlash, jam/thermal |
| Adaptive tendon gripper mechanism | Grasping; STM32 | SC09 candidate; tendon details TBD | `gripper.left/right`; protected actuator driver | Palm/fingers/tendon routes; motion safety | `VERIFY_ON_ARRIVAL` | Component matrix/current CAD concept; actuator, tendon, force, travel, pinch risk, retention/cycle life |
| P20/15 12 V electromagnet-class tool | Magnetic tool; STM32/tool controller | 12 V class; switching/sensing/connector TBD | `tool.magnet.*`; protected tool semantic driver | Tool housing/quick swap/thermal; safety-relevant dropped-object risk | `VERIFY_ON_ARRIVAL` | Component matrix/CAD; exact magnet, pull vs gap/material, current/temperature, residual force, retention |
| STM32C011-class tool MCU | Tool-local control; STM32-owned domain | UART/ADC/PWM/watchdog class; exact board TBD | `tool.controller.*`; protected embedded tool module | Tool volume/connector; safety-relevant | `UNDECIDED` | Component matrix class-level; exact MCU/board, power, firmware/debug, dimensions |
| Independent RS-485 per wrist | Tool data link; STM32 | Physical transceiver/connector/baud TBD | `tool.link.left/right`; protected tool-link service | Wrist connector/cable loop; safety/fault-containment relevant | `WAITING_FOR_VERIFIED_INPUTS` | Component matrix architecture only; exact transceiver, wiring, termination, connector, fault behavior |
| DMM-4026 I2S-class microphones, two | Audio capture; ESP32-S3 | I2S class; exact variant/power TBD | `audio.input.*`; ESP32 audio embedded module | Head ports, acoustic isolation/cable; non-safety | `VERIFY_ON_ARRIVAL` | Component matrix; exact units, dimensions, port/orientation, sensitivity/noise, interface/voltage |
| PUI AS04004PO-R-class speaker | Audio output; ESP32-S3 | Amp connection/power TBD | `audio.output`; ESP32 audio embedded module | Speaker chamber/vent; non-safety with thermal/acoustic considerations | `VERIFY_ON_ARRIVAL` | Component matrix/CAD envelope; exact speaker, dimensions, impedance/power, excursion, clearance |
| MAX98357A-class I2S amplifier | Speaker drive; ESP32-S3 | I2S class; exact carrier/power TBD | `audio.amplifier`; ESP32 audio embedded module | Audio zone/thermal/noise; non-safety | `VERIFY_ON_ARRIVAL` | Component matrix; exact board, pins, gain, voltage/current, thermal/noise |
| Head/arm/wheel hard stops, shutdown feet, brackets, fasteners, spacers | Structure/restraint; passive | Mechanical; final sizes TBD | physical assembly, no executable extension | All modules; safety/serviceability | `VERIFY_ON_ARRIVAL` | v0.3 CAD geometry only; material, print/process, thread, length, insert fit, load, clearance |
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

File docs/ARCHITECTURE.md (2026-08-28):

# System Architecture — Direction v0.1

## Principle

ZI-E's body should remain a safe real-time robot controller, while heavy AI runs outside the body initially.

## Initial system

```text
                       ┌──────────────────────────────┐
                       │          LAPTOP              │
                       │                              │
 Camera/Audio/Sensors ─► Vision / Speech / LLM       │
                       │ Behavior / Memory / Database │
                       │                              │
 Safe intents/commands ◄                              │
                       └──────────────┬───────────────┘
                                      │ Wi-Fi
                                      │
                       ┌──────────────▼───────────────┐
                       │          ZI-E BODY           │
                       │                              │
                       │ Robot controller             │
                       │ Motor/servo control          │
                       │ Local safety                 │
                       │ Telemetry                    │
                       │ Camera/mic transport         │
                       │ Sensor transport             │
                       └──────────────────────────────┘
```

## Local robot responsibilities

Expected:
- Wi-Fi communications;
- actuator control;
- sensor acquisition;
- camera/microphone data transport;
- telemetry;
- emergency stop;
- collision / motion safety;
- state machine;
- safe command validation;
- local fallback behavior where useful.

Not intended as the primary responsibility:
- main LLM;
- long-term personal memory;
- main vector/database system;
- unrestricted AI decisions;
- cloud secrets embedded in distributable firmware.

## Laptop brain responsibilities

Candidate responsibilities:
- speech recognition;
- text-to-speech orchestration;
- vision inference;
- LLM reasoning;
- long-term memory;
- user preferences;
- episodic memory;
- behavior planning;
- database;
- learning/adaptation logic;
- diagnostics and development tooling.
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

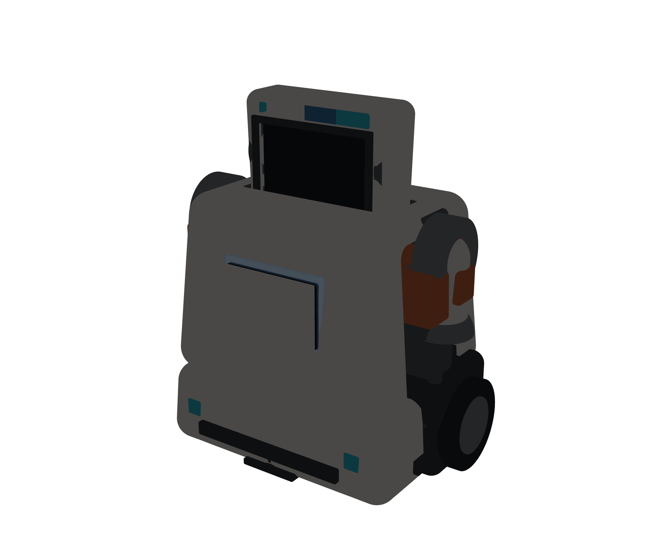
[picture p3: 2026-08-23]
mechanical/cad/current/renders/ZI-E_v0_3_SLEEP_iso.png

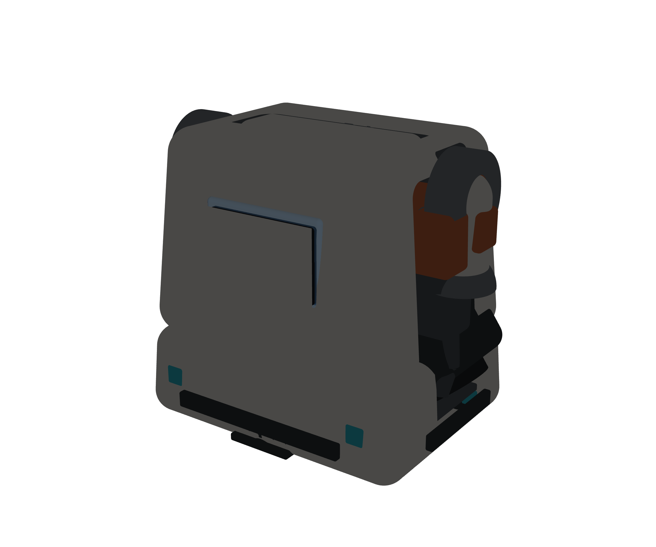
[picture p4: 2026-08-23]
mechanical/cad/current/renders/ZI-E_v0_3_SHUTDOWN_iso.png

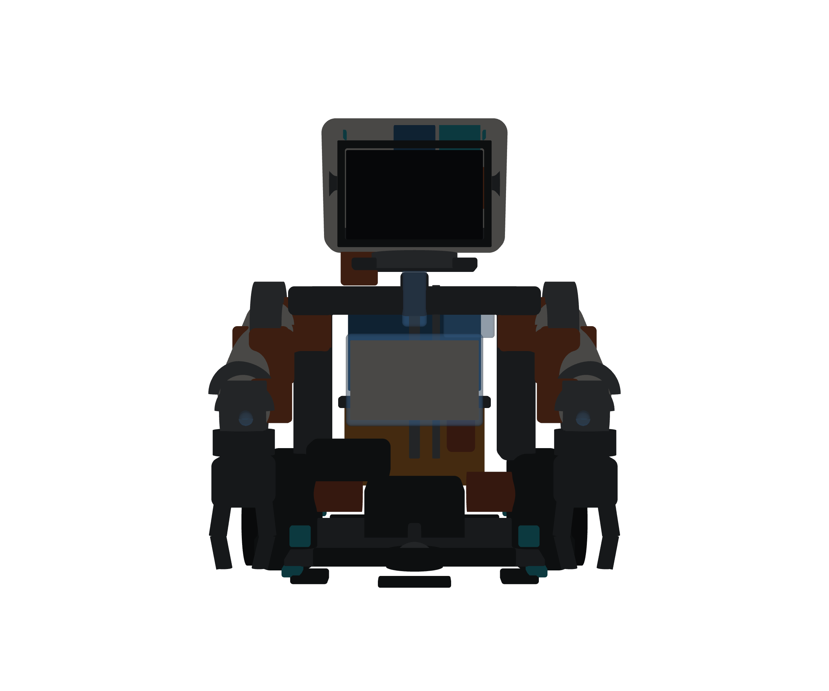
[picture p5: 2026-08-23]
mechanical/cad/current/renders/ZI-E_v0_3_CUTAWAY_front.png

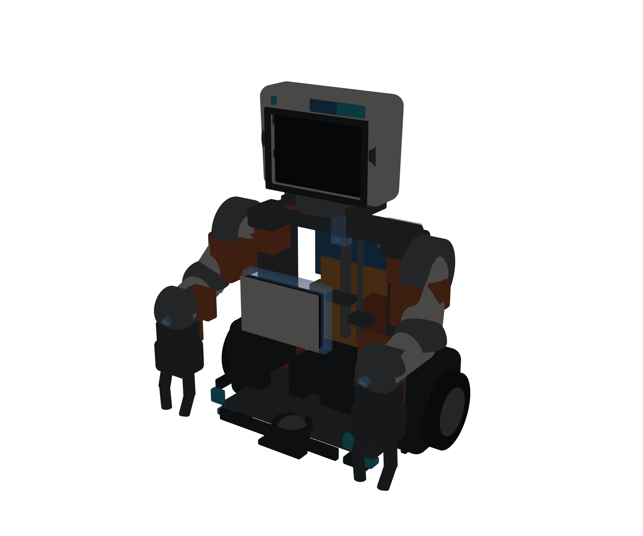
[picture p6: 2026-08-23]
mechanical/cad/current/renders/ZI-E_v0_3_CUTAWAY_iso.png

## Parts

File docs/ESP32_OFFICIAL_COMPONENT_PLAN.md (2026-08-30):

# ESP32 Official Component Plan

Status: development dependency evaluation; no component or production SDK version is
frozen, downloaded, or vendored. Hardware bindings remain disabled.

| Capability | Preferred source | Evaluation range | License review | Zi-E wrapper | Hardware dependency | Pre-HW-002 build |
|---|---|---|---|---|---|---|
| Wake/AFE/AEC/NR/AGC | `espressif/esp-sr` | donor-tested `~2.4.7`; re-resolve with selected IDF | Component-specific review required | `WakeDetector` / DSP capability adapter | microphones, channel/reference topology, memory | Interface only; DSP deferred |
| Camera | `espressif/esp32-camera` | donor `^2.1.6` | Apache-style/component notice to verify | `CameraDevice` | exact sensor, bus, GPIO, clock, PSRAM | Component resolution possible; init disabled |
| Alternate video stack | `espressif/esp_video` | donor `^2.3.0` | Component-specific review required | same Camera abstraction | verified controller/sensor need | Deferred unless board requires it |
| Codec primitives | `espressif/esp_audio_codec` | donor `~2.5.0` | Component-specific review required | `AudioEncoder/Decoder` | negotiated format | Candidate buildable |
| Codec device | `espressif/esp_codec_dev` | donor `~1.5.6` | Component-specific review required | `AudioCapture/Playback` driver | exact codec/I2S/I2C binding | Init deferred |
| Audio effects | `espressif/esp_audio_effects` | donor `~1.3.0` | Component-specific review required | DSP capability adapter | audio topology and measured performance | Deferred |
| Renderer | `lvgl/lvgl`, `esp_lvgl_port` | donor `~9.5.0`, `~2.8.0` | MIT plus port notice review | Zi-E Face render backend | controller/resolution/bus/memory | Model/build boundary only |
| RGB | `espressif/led_strip` | donor `~3.0.2` | Component-specific review required | semantic RGB effects | HW-008 identity, voltage/timing | Init deferred |

Development toolchain candidate: latest stable official ESP-IDF 6.0.x, tested in a
matrix against 5.5.2 before repository lock. This is not a physically verified board
release. Selection requires official component resolution, ESP32-S3 generic no-pin
smoke build, then HW-002 identity/flash/PSRAM/camera/display/audio comparison.

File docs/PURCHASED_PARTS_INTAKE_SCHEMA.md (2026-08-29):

# Purchased-Parts / Google Sheet Intake Contract

## 0.04 working-copy workflow

Google Sheet or the HUD form is intake convenience. Export CSV, preview and explicitly
confirm it in Control Center, use the contained inventory as the engineering working
copy, review evidence, then export an approved repository snapshot when appropriate.
Google credentials stay outside the repository; do not treat two mutable sources as
simultaneously authoritative.

Use the exact columns in `docs/templates/PURCHASED_PARTS_INTAKE_TEMPLATE.csv`. The
template intentionally contains no invented inventory rows. One row represents one
exact purchasable variant or uniquely identified assembly; split rows when revision,
source, controller ownership or disposition differs.

## Field contract

| Field | Rule |
|---|---|
| `inventory_id` | Stable user-assigned ID; never reuse after replacement |
| `part_name`, `manufacturer`, `model_exact_variant` | Transcribe labels/order record; do not normalize away suffix/revision |
| `quantity`, `purchase_status` | Numeric count and controlled procurement state: existing/required/ordered/received/quarantined/returned |
| `procurement_role` | Controlled planning role: existing/required/substitute_candidate; this does not approve a substitute |
| `purchase_link_reference`, `photo_reference` | Provenance links/IDs; photos must show label and relevant connectors/dimensions |
| `controller_ownership` | Closed intent: ESP32-S3/STM32/host/passive; ambiguity stays blank/UNDECIDED |
| `function`, `interface_documented` | Semantic role and datasheet interface, not guessed pins |
| `voltage_documented`, `current_documented` | Datasheet values with source/conditions/units |
| `voltage_measured`, `current_measured` | Blank until instrumented measurement with condition/log |
| `connector` | Exact family/part/cavity/key/orientation when verified; not “JST” alone |
| `zie_logical_slot` | Stable semantic slot such as `cliff.downward.front_left` |
| `driver_extension` | Protected embedded driver or semantic extension responsibility; never raw plugin authority |
| `hardware_profile_mapping` | Exact profile requirement/capability candidate; activation still requires registry/commissioning |
| `cad_status` | absent/envelope/modelled/fit_coupon_passed/received_fit_verified/rework |
| `dimensions_documented`, `weight_documented` | Datasheet/listing value plus source and units |
| `dimensions_measured`, `weight_measured` | Blank until received-part measurement |
| `safety_criticality` | critical/high/medium/low with rationale in notes |
| `verify_on_arrival` | yes until identity, condition, fit, interface and ratings are reconciled |
| `decision_keep_replace_undecided` | Product Owner disposition; substitute candidates remain UNDECIDED |
| `notes`, `evidence_source`, `reviewer`, `date_received` | Conditions, conflicts, provenance and audit trail |

## Intake workflow

1. Export/copy the sheet without dropping columns; retain original revision/time.
2. Validate required IDs, controlled procurement states/roles, quantities and duplicate exact items.
3. Link order evidence and label photos; quarantine mismatches/counterfeit uncertainty.
4. Compare the row to `HARDWARE_SOURCE_OF_TRUTH_RECONCILIATION.md`; record conflicts.
5. Measure only with recorded method/instrument/condition; never copy CAD into measured
   fields.
6. Product Owner decides KEEP/REPLACE/UNDECIDED where evidence changes a candidate.
7. Update Device Identity, Hardware Profile candidate and CAD together; no silent
   rebinding/substitution.

The Sheet becomes authoritative for physical inventory only after review. It does not
by itself prove electrical suitability, safety, commissioning or execution authority.

## Control Center 0.03 compatibility decision

The 32 columns above remain unchanged and authoritative for CSV interchange. Runtime
metadata is intentionally separate in ignored `runtime/inventory/active.json`:
`physical_status`, `storage_location`, evidence/review lifecycle, explicit candidate
match, driver state, commissioning/measurement requirements, conflicts, verification,
tombstone/history, and revision timestamps. Export retains exact canonical ordering.

For ordinary entry, users need only: `inventory_id`, `part_name`, `manufacturer`,
`model_exact_variant`, `quantity`, `physical_status` (`RECEIVED`, `ORDERED`,
`NOT_BOUGHT`, `UNKNOWN`), purchase reference, photo reference, storage location, and
notes. Missing engineering values remain unknown and move to the separate review.

### Google Sheet without API credentials

1. Maintain the ten simple user columns in the Sheet.
2. Export as CSV and place values into the matching canonical template columns.
3. Preview the canonical CSV in Control Center; resolve validation/conflicts.
4. Explicitly confirm persistence with the current inventory revision.
5. Perform engineering review, reconciliation, and evidence-backed decisions.

Google API synchronization and credentials are deliberately absent.

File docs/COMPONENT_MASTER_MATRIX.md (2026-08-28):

# Component Master Matrix

This is the quick lookup table. `Primary` means current first-choice; `Backup` means an intentional substitute, not an equal recommendation. Prices are deliberately omitted because they are volatile; re-check before purchasing.

This is a design-choice quick reference, not physical inventory. The canonical
reconciliation/status/provenance layer is
`HARDWARE_SOURCE_OF_TRUTH_RECONCILIATION.md`; purchased items must enter through
`PURCHASED_PARTS_INTAKE_SCHEMA.md`. `KEEP` below never means physically verified.

| Subsystem | Primary | Backup(s) / Switch Condition | Status |
|---|---|---|---|
| Display | 3.5" IPS touch, ILI9488, 480×320 landscape | EastRising/BuyDisplay or equivalent documented panel if FPC/touch IC/availability fails | KEEP, verify exact panel |
| Belly Light Matrix | IS31FL3741 13×9 RGB prototype + secret-until-lit optical insert | Wider custom IS31FL3741-class matrix after optical/power test | KEEP architecture, VERIFY optics/thermal |
| Camera | OV5640 5MP AF | OV2640 if budget forces it | KEEP |
| Head laser rangefinder | VL53L1X 940 nm Class-1 ToF, up to 4 m | TF-Luna 8 m if >4 m / >50 Hz required; TFmini-S for longer-range requirement | KEEP architecture, VERIFY optics/calibration |
| Multimedia MCU | ESP32-S3-WROOM-1-N16R8 | Same class/PSRAM variant only after pin/resource audit | KEEP |
| Safety MCU | STM32G0B1RET6 | Same-family equivalent only after I/O/timer/CAN audit | KEEP |
| Main MCU link | Classical CAN/TWAI | UART only as development fallback | KEEP |
| IMU | LSM6DSOX | BMI270 | KEEP |
| Downward cliff | 4× VL53L4CD | Add mechanical feelers if optical blind spots remain | KEEP architecture |
| Horizontal proximity | 4× VL53L4CD | 2× if cost/space pressure, bumper remains | CONDITIONAL |
| Bumper | 4× D2F-L class | D2HW sealed class | KEEP architecture |
| Wheel motor | 25SG-370CA-78-EN class, 12V encoded | Equivalent 25mm encoded gearmotor meeting envelope/performance | CONDITIONAL on final mass |
| Wheel driver | 2× DRV8876 | Equivalent protected H-bridge after current/thermal audit | KEEP |
| Ball caster | POM ball-caster cartridge | Pololu #2692 / custom | CONDITIONAL geometry |
| Battery | 3S2P Molicel M35A class | Trusted equivalent 18650 only after current/energy audit | KEEP architecture |
| Pack protection | BQ7791500 class | Exact family variant after pack/electrical design | CONDITIONAL implementation |
| Charger V1 | Certified 12.6V ~2A CC/CV external | Integrated USB-C PD later | KEEP V1 |
| General bucks | AP62300 class | Equivalent efficiency/thermal parts | KEEP class |
| Safety 3.3V | TPS62162 class | Equivalent isolated safety supply | KEEP class |
| Arm/head protection | TPS25947/eFuse class | Equivalent current-limited protected switch | KEEP class |
| Shoulder | STS3215-C018, 2/arm | Ratio/actuator upgrade only if load/thermal test fails | CONDITIONAL physical test |
| Elbow | HL2915-C001 + ~2:1 belt | STS3215 if torque/thermal margin fails | CONDITIONAL physical test |
| Telescope | N20 encoder + T5×2 | Faster N20 / changed lead after speed test | KEEP architecture |
| Forearm Roll | SC09 | ST3036 if precision/load fails | CONDITIONAL |
| Wrist Pitch | SC09 + ~2:1 | ST3036 / HL2915 if tool load fails | CONDITIONAL |
| Pan | SC09 + 1:1 | ST3036 if jitter/backlash unacceptable | KEEP initial |
| Tilt | SC09 + ~2:1 | ST3036 precision / HL2915 torque | CONDITIONAL on head mass |
| Head Lift | N20 encoder + T5×2 | Faster N20 / stepper only if justified | KEEP architecture |
| Gripper | SC09 adaptive tendon differential | Stronger actuator if grasp tests require | KEEP concept |
| Magnetic Tool | P20/15 12V electromagnet class | Larger magnet / EPM only if requirements justify | CONDITIONAL physical test |
| Tool MCU | STM32C011 class | Similar low-cost MCU with required UART/ADC/PWM/watchdog | KEEP class |
| Tool data | Independent RS-485 per wrist | — | KEEP |
| Microphones | 2× DMM-4026 I2S class | T5848; 4-mic only after testing | KEEP initial |
| Speaker | AS04004PO-R class | AS02404PO if packaging forces smaller unit | CONDITIONAL CAD |
| Audio amp | MAX98357A | Equivalent I2S class-D | KEEP |

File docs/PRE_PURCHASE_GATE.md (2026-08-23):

# ZI-E Pre-Purchase Gate

Do not bulk-order parts merely because a CAD envelope fits. Buy the minimum parts needed to retire the highest-risk uncertainties first.

## Phase A — cheap evidence before bulk purchase
1. One 3.5-inch display candidate + confirm exact pinout/touch IC.
2. One OV5640 AF module.
3. One VL53L1X rangefinder carrier/sample for head-brow optical and alignment tests.
4. One ESP32-S3 N16R8 development carrier and one STM32G0B1 test board/carrier.
5. One STS3215, one HL2915, one SC09, one N20 encoder motor.
6. One wheel motor + DRV8876 test channel.
7. One VL53L4CD breakout initially; surface tests before buying all 8 sensors.
8. One IS31FL3741 13×9 belly-matrix breakout + several optical-window coupons.
9. One P20/15 magnet sample (two if generic supplier quality is uncertain).

## Mandatory bench tests before batch order
- Servo ID/model/baud discovery and safe low-torque commissioning.
- Sustained rated-load temperature, backlash, repeatability, audible noise.
- Head cable loop through Pan/Tilt/Lift full travel and jam/power-loss behavior.
- Head laser rangefinder: known-distance accuracy, dark/daylight, black/glossy/glass targets, final cover-window coupons, crosstalk calibration, Pan/Tilt stability and camera-axis alignment.
- Arm dummy-load test using estimated link/tool masses.
- Wheel traction/braking/current on representative desk surfaces.
- Cliff sensor surface matrix: white, matte black, glossy black, wood, metal, mirror, clear glass, tablecloth, edge shapes, daylight, dirty sensor.
- Belly matrix optical coupon: hidden off-state, time/icon readability, daylight, current, heat, light bleed.
- Magnet pull force vs steel size/thickness/paint/gap and coil temperature.
- Power transient/regen and brownout fault injection.

## Bulk purchase condition
A part becomes `BUY-BATCH` only after its test result is stored in `/tests/results/` and the component matrix status is changed from `CONDITIONAL` to `VERIFIED`.

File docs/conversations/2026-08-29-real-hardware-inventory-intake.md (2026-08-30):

# 2026-08-29 — Real hardware inventory intake and reconciliation

The session continued from pushed Control Center 0.04 commit
`878c32cb554cb9d1d05b6c73e5c7eb024c0e3aae` without redesigning the Control Center.
The original `Zi-E_Hardware_Master_Inventory.xlsx` was read without modification and
identified by SHA-256
`378b06f0f34baa188b7b496d3e0a7f0e12e1b043fe082e0ca83a23e3685660b6`.

A deterministic, workbook-specific converter produced the canonical 32-column CSV
snapshot and imported it through the existing validated revisioned store. The active
working inventory contains `HW-001` through `HW-031`: 31 rows, 167 units, 29 received,
one ordered camera board, and one receipt-confirmed multimeter whose physical status
remains unknown. All evidence remains unreviewed and no row is verified. `HW-032` and
`HW-033` were excluded as candidate-only seller references.

The ordered camera remains blocked on arrival evidence. The workbook's seller camera
map, GPIO allocation, full wiring, and firmware defines were not imported as physical
wiring or production pins. VL53L0X-versus-VL53L1X and RGB-breakout-versus-belly-matrix
mismatches are explicit and quarantined for decision. The photographed 5 V / 3 A board
remains electrically blocked. Missing STM32, controller-link/CAN, motion, drive,
battery/BMS, protected power, and other required hardware remain missing.

Targeted intake/inventory/reconciliation regression tests pass. Full App validation
passed 118 tests; the fallback runner passed 44 tests. Compileall, PowerShell parsing,
HTML parsing, JavaScript syntax, the canonical CSV contract, source-hash recheck, and
`git diff --check` passed. No commit or push was performed.

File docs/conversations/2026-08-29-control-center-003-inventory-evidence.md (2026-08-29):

# 2026-08-29 — Control Center 0.03 inventory and evidence foundation

The Product Owner requested one coherent software-side purchased-hardware workflow so
the next human activity is data entry rather than more architecture. Work continued
on the complete staged 0.02 tree at unchanged HEAD `1c1cf43`, without reset, stash,
discard, history rewrite, commit, or push.

The exact 32-column canonical CSV was preserved. A separate ignored, project-owned,
revisioned JSON store now holds 0.03 metadata and tombstones. It provides validated
atomic saves, optimistic revisions, one previous revision, fixed rollback, strict
create/edit/review operations, preview/commit import, deterministic export, search,
filters, counters, inspector, evidence/decision controls, reconciliation, blockers,
commissioning dependencies, and Phase 2B2 missing-input visibility.

The store begins empty. Candidate documents never seed purchased inventory. VERIFIED
requires an explicit reviewed-evidence transition and cannot be produced by receipt,
model text, links, photos, import, candidate match, simulator, or tests. No hardware,
HostRuntime, profile, commissioning, developer, or robot authority was added.

Next human workflow: enter actual parts or export the simple Google Sheet to canonical
CSV; preview and persist; attach metadata references; transcribe exact labels; record
documented versus measured evidence separately; reconcile candidates, ownership,
slots/Profile, drivers and CAD; then have an engineer review conflicts and decisions.

Fresh validation passed 104 App pytest tests and 44 fallback tests, compileall,
PowerShell/HTML/JavaScript parsing, exact 32-column schema/migration checks, and diff
checking. Independent adversarial findings were repaired: explicit conflicts and
candidate mismatches block verification, review changes cleanly revoke verification,
unknown CSV controlled values are rejected, revision saves are locked against
concurrent stale writes, and blocker rows navigate to their purchased item.

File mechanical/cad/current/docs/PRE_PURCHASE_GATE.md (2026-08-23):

# ZI-E Pre-Purchase Gate

Do not bulk-order parts merely because a CAD envelope fits. Buy the minimum parts needed to retire the highest-risk uncertainties first.

## Phase A — cheap evidence before bulk purchase
1. One 3.5-inch display candidate + confirm exact pinout/touch IC.
2. One OV5640 AF module.
3. One ESP32-S3 N16R8 development carrier and one STM32G0B1 test board/carrier.
4. One STS3215, one HL2915, one SC09, one N20 encoder motor.
5. One wheel motor + DRV8876 test channel.
6. One VL53L4CD breakout initially; surface tests before buying all 8 sensors.
7. One IS31FL3741 13×9 belly-matrix breakout + several optical-window coupons.
8. One P20/15 magnet sample (two if generic supplier quality is uncertain).

## Mandatory bench tests before batch order
- Servo ID/model/baud discovery and safe low-torque commissioning.
- Sustained rated-load temperature, backlash, repeatability, audible noise.
- Head cable loop through Pan/Tilt/Lift full travel and jam/power-loss behavior.
- Arm dummy-load test using estimated link/tool masses.
- Wheel traction/braking/current on representative desk surfaces.
- Cliff sensor surface matrix: white, matte black, glossy black, wood, metal, mirror, clear glass, tablecloth, edge shapes, daylight, dirty sensor.
- Belly matrix optical coupon: hidden off-state, time/icon readability, daylight, current, heat, light bleed.
- Magnet pull force vs steel size/thickness/paint/gap and coil temperature.
- Power transient/regen and brownout fault injection.

## Bulk purchase condition
A part becomes `BUY-BATCH` only after its test result is stored in `/tests/results/` and the component matrix status is changed from `CONDITIONAL` to `VERIFIED`.

## v0.3 laser rangefinder
Buy only one VL53L1X carrier/sample first. Verify range accuracy, cover-window optical performance, camera alignment and contamination sensitivity before custom brow PCB or bulk order.

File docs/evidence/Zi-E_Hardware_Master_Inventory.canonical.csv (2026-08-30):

inventory_id | part_name | manufacturer | model_exact_variant | quantity | purchase_status | procurement_role | purchase_link_reference | photo_reference | controller_ownership | function | interface_documented | voltage_documented | current_documented | voltage_measured | current_measured | connector | zie_logical_slot | driver_extension | hardware_profile_mapping | cad_status | dimensions_documented | dimensions_measured | weight_documented | weight_measured | safety_criticality | verify_on_arrival | decision_keep_replace_undecided | notes | evidence_source | reviewer | date_received
HW-001 | ESP32-S3 development board |  | ESP32-S3-N16R8 (non-camera board) | 1 | received | existing |  | IMG_0384–IMG_0387 |  | Bench development and backup controller | GPIO / SPI / I2C / I2S / USB | Board normally powered by USB/5 V; module itself 3.0–3.6 V |  |  |  |  |  |  |  |  |  |  |  |  |  | yes | UNDECIDED | Workbook category: Controller | Workbook role: Spare | Evidence wording: Photo-confirmed | Confidence wording: High | Reference-family specifications (not measured): Dual-core Xtensa LX7 up to 240 MHz; 16 MB flash; 8 MB Octal PSRAM; 2.4 GHz Wi-Fi; Bluetooth 5 LE | Software need (not implementation proof): Arduino-ESP32 or ESP-IDF | Do not assume dev-board pinout from the module name. Identify exact board model and USB bridge before wiring. | Zi-E_Hardware_Master_Inventory.xlsx | Parts Inventory | HW-001
HW-002 | ESP32-S3 camera development board |  | ESP32-S3 N16R8 with OV5640 5 MP camera | 1 | ordered | existing | Online seller screenshots photo_1, photo_4, photo_7–photo_10 (not physical-arrival proof) |  |  | Primary Zi-E controller with camera | Camera DVP / GPIO / SPI / I2C / I2S / USB / microSD | USB-C or external 5 V per seller listing |  |  |  |  |  |  |  |  |  |  |  |  |  | yes | UNDECIDED | Workbook category: Controller + Camera | Workbook role: Primary design target | Evidence wording: Ordered; awaiting arrival | Confidence wording: Medium | Reference-family specifications (not measured): Seller listing: dual-core Xtensa LX7 up to 240 MHz; 16 MB flash; 8 MB PSRAM; OV5640 5 MP camera; 2.4 GHz Wi-Fi; Bluetooth LE 5; microSD; USB-C and USB OTG. Claims up to 45 GPIO, but camera and board circuitry consume/reserve pins. | Software need (not implementation proof): Arduino-ESP32 + esp32-camera | Seller example pin map is recorded in Camera Pin Map. Verify PCB revision, OV5640 marking and every GPIO on arrival before flashing or wiring. | Seller camera identity and pin maps are provisional procurement references only; arrival review is required before wiring or firmware pin freeze. | Zi-E_Hardware_Master_Inventory.xlsx | Parts Inventory | HW-002
HW-003 | 3.5-inch SPI TFT LCD module |  | ILI9488; PCB marked 3.5 TFT SPI 480×320 V1.0 | 1 | received | existing | SKU 2061001103 | IMG_0419–IMG_0424 |  | Main user interface | SPI; separate touch SPI; microSD SPI | Verify PCB input voltage and logic levels |  |  |  |  |  |  |  |  |  |  |  |  |  | yes | UNDECIDED | Workbook category: Display | Workbook role: Primary | Evidence wording: Photo + receipt confirmed | Confidence wording: High | Reference-family specifications (not measured): 480×320 pixels; SPI display; microSD socket; touch interface present, controller not confirmed | Software need (not implementation proof): TFT_eSPI; touch library only after controller confirmation | ILI9488 often needs board-specific library configuration. Verify touch-controller IC and every printed pin label. | Zi-E_Hardware_Master_Inventory.xlsx | Parts Inventory | HW-003
HW-004 | Stereo DAC module |  | PCM5102 / PCM5102A module | 1 | received | existing | SKU 3011013038 | IMG_0395–IMG_0399 |  | Digital audio conversion | I2S | Verify module VIN and logic arrangement |  |  |  |  |  |  |  |  |  |  |  |  |  | yes | UNDECIDED | Workbook category: Audio output | Workbook role: Primary | Evidence wording: Photo + receipt confirmed | Confidence wording: High | Reference-family specifications (not measured): Stereo audio DAC; reference IC supports I2S/left-justified audio up to 32-bit/384 kHz and typical 112 dB SNR | Software need (not implementation proof): Arduino-ESP32 built-in I2S API | Module pin names and onboard regulator/jumpers vary. Confirm BCK, LRCK, DIN, GND and power labels. | Zi-E_Hardware_Master_Inventory.xlsx | Parts Inventory | HW-004
HW-005 | Class-D amplifier module |  | PAM8403, 2 × 3 W class-D | 1 | received | existing | SKU 3011017003 | IMG_0404–IMG_0407 |  | Drive the two speakers | Analog stereo in; bridge-tied speaker outputs | 2.5–5.5 V |  |  |  |  |  |  |  |  |  |  |  |  |  | yes | UNDECIDED | Workbook category: Audio output | Workbook role: Primary | Evidence wording: Photo + receipt confirmed | Confidence wording: High | Reference-family specifications (not measured): 2.5–5.5 V supply; 3 W/channel rating is specified at 5 V into 4 Ω near 10% THD; output into 8 Ω speakers will be lower | Software need (not implementation proof): None (analog hardware) | Speaker negatives are not ground. Never join L−/R− or connect either output to ground. | Zi-E_Hardware_Master_Inventory.xlsx | Parts Inventory | HW-005
HW-006 | Microphone amplifier module |  | MAX9814 with AGC | 1 | received | existing | SKU 3011017071 | Photo set |  | Voice/audio sensing | Analog output to ESP32 ADC | Verify module VIN; IC reference supply 2.7–5.5 V |  |  |  |  |  |  |  |  |  |  |  |  |  | yes | UNDECIDED | Workbook category: Audio input | Workbook role: Primary | Evidence wording: Photo + receipt confirmed | Confidence wording: High | Reference-family specifications (not measured): Low-noise microphone amplifier with automatic gain control and analog output | Software need (not implementation proof): ESP32 ADC API; no dedicated driver | No software driver is required; ADC sampling and bias handling are firmware tasks. Verify module GAIN/AR pins. | Zi-E_Hardware_Master_Inventory.xlsx | Parts Inventory | HW-006
HW-007 | Laser time-of-flight module |  | VL53L0X / GY-53 / CJMCU style | 1 | received | existing | SKU 3011007068 | Photo set |  | Proximity and distance sensing | I2C; optional XSHUT/GPIO | Sensor IC supply differs from breakout VIN; verify regulator/level shifting |  |  |  |  |  |  |  |  |  |  |  |  |  | yes | UNDECIDED | Workbook category: Distance sensor | Workbook role: Primary | Evidence wording: Photo + receipt confirmed | Confidence wording: High | Reference-family specifications (not measured): I2C time-of-flight distance sensor; range can approach 2 m only under favorable target and lighting conditions | Software need (not implementation proof): VL53L0X Arduino library | Confirm exact breakout pin labels and I2C voltage compatibility before power-up. | Received VL53L0X/GY-53/CJMCU-style hardware does not satisfy the VL53L1X head-rangefinder candidate without an explicit KEEP/REPLACE decision. | Zi-E_Hardware_Master_Inventory.xlsx | Parts Inventory | HW-007
HW-008 | Addressable RGB LED breakout |  | WS2812/WS2811 family | 2 | received | existing | SKU 3011007040 | IMG_0400–IMG_0403 |  | Status and effects lighting | Single-wire data, DI/DO | Typically 5 V LED power; verify module |  |  |  |  |  |  |  |  |  |  |  |  |  | yes | UNDECIDED | Workbook category: Lighting | Workbook role: Primary | Evidence wording: Photo + receipt confirmed | Confidence wording: High | Reference-family specifications (not measured): Individually addressable RGB LED; typical one-wire 800 kHz protocol; exact LED variant not confirmed | Software need (not implementation proof): Adafruit NeoPixel | Use common ground. A 3.3 V data signal may need level shifting depending on supply/noise margin. | These two RGB breakouts do not satisfy the different belly-matrix design candidate without an explicit KEEP/REPLACE decision. | Zi-E_Hardware_Master_Inventory.xlsx | Parts Inventory | HW-008
HW-009 | Round speaker |  | 8 Ω, 2 W, 40 mm | 3 | received | existing | SKU 2200001097 | IMG_0404–IMG_0407 |  | Two active speakers plus one spare | Two-wire audio | Driven from amplifier only |  |  |  |  |  |  |  |  |  |  |  |  |  | yes | UNDECIDED | Workbook category: Audio output | Workbook role: Primary | Evidence wording: Photo + receipt confirmed | Confidence wording: High | Reference-family specifications (not measured): 8 Ω nominal impedance; 2 W marked/rated; approximately 40 mm diameter | Software need (not implementation proof): None | PAM8403 output will be below its 4 Ω headline power when using 8 Ω speakers. | Zi-E_Hardware_Master_Inventory.xlsx | Parts Inventory | HW-009
HW-010 | Switching power-supply board |  | 5 V / 3 A seller description | 1 | received | existing | SKU 2210001675 | Photo set |  | System 5 V rail | Power input/output | Input TO VERIFY; output nominal 5 V |  |  |  |  |  |  |  |  |  |  |  |  |  | yes | UNDECIDED | Workbook category: Power | Workbook role: Primary | Evidence wording: Photo + receipt confirmed | Confidence wording: Medium | Reference-family specifications (not measured): Seller-rated 5 V, 3 A; topology, input range, isolation and protections not confirmed | Software need (not implementation proof): None (hardware verification required) | Do not connect until input/output terminals, polarity, isolation and safe current capability are identified. | Electrically blocked for system power pending input range, terminals, polarity, isolation, protection, and safe-current verification. | Zi-E_Hardware_Master_Inventory.xlsx | Parts Inventory | HW-010
HW-011 | Solderless breadboard |  | MB-102 mini, 400 tie points | 1 | received | existing | SKU 2280001012 | IMG_0425–IMG_0426 |  | Bench prototyping | 2.54 mm contacts | Passive |  |  |  |  |  |  |  |  |  |  |  |  |  | yes | UNDECIDED | Workbook category: Prototyping | Workbook role: Bench | Evidence wording: Photo + receipt confirmed | Confidence wording: High | Reference-family specifications (not measured): 400 tie points; package shows 300 terminal points + 100 distribution points; approx. 82 × 55 × 8.5 mm | Software need (not implementation proof): None | Not suitable for high current speaker/power paths. | Zi-E_Hardware_Master_Inventory.xlsx | Parts Inventory | HW-011
HW-012 | Perforated prototyping board |  | 1000-point perfboard | 1 | received | existing | SKU 2231001003 | IMG_0380–IMG_0383 |  | Permanent prototype assembly | 2.54 mm through-hole grid (verify) | Passive |  |  |  |  |  |  |  |  |  |  |  |  |  | yes | UNDECIDED | Workbook category: Prototyping | Workbook role: Primary | Evidence wording: Photo + receipt confirmed | Confidence wording: High | Reference-family specifications (not measured): 1000 solder points; exact dimensions and copper pattern should be measured | Software need (not implementation proof): None | Plan ground and power distribution before soldering. | Zi-E_Hardware_Master_Inventory.xlsx | Parts Inventory | HW-012
HW-013 | Male pin header |  | 1 × 40, standard breakaway | 5 | received | existing | SKU 2160001002 | Photo set |  | Module and perfboard connections | Through-hole | Passive |  |  |  |  |  |  |  |  |  |  |  |  |  | yes | UNDECIDED | Workbook category: Interconnect | Workbook role: Primary | Evidence wording: Photo + receipt confirmed | Confidence wording: High | Reference-family specifications (not measured): 40 positions per strip; likely 2.54 mm pitch | Software need (not implementation proof): None | Verify pitch against modules before soldering. | Zi-E_Hardware_Master_Inventory.xlsx | Parts Inventory | HW-013
HW-014 | Jumper-wire ribbon |  | Female-to-female, 20 cm, 40 wires | 1 | received | existing | SKU 2291006001 | Photo set |  | Bench interconnect | 2.54 mm female sockets | Passive |  |  |  |  |  |  |  |  |  |  |  |  |  | yes | UNDECIDED | Workbook category: Interconnect | Workbook role: Bench | Evidence wording: Photo + receipt confirmed | Confidence wording: High | Reference-family specifications (not measured): 40 separable Dupont-style leads, approximately 20 cm | Software need (not implementation proof): None | Use only for low-current signals and light loads. | Zi-E_Hardware_Master_Inventory.xlsx | Parts Inventory | HW-014
HW-015 | Jumper-wire ribbon |  | Male-to-female, 20 cm, 40 wires | 1 | received | existing | SKU 2291006004 | Photo set |  | Bench interconnect | 2.54 mm male/female | Passive |  |  |  |  |  |  |  |  |  |  |  |  |  | yes | UNDECIDED | Workbook category: Interconnect | Workbook role: Bench | Evidence wording: Photo + receipt confirmed | Confidence wording: High | Reference-family specifications (not measured): 40 separable Dupont-style leads, approximately 20 cm | Software need (not implementation proof): None | Use only for low-current signals and light loads. | Zi-E_Hardware_Master_Inventory.xlsx | Parts Inventory | HW-015
HW-016 | USB-A to USB-C cable |  | Shielded, 30 cm | 1 | received | existing | SKU 2291004188 | IMG_0408–IMG_0411 |  | Programming and power | USB | 5 V USB plus data if cable is data-capable |  |  |  |  |  |  |  |  |  |  |  |  |  | yes | UNDECIDED | Workbook category: Cable | Workbook role: Bench | Evidence wording: Photo + receipt confirmed | Confidence wording: High | Reference-family specifications (not measured): USB-A to USB-C; seller lists 30 cm and shielded construction | Software need (not implementation proof): None | Verify the cable carries data; some USB cables are charge-only. | Zi-E_Hardware_Master_Inventory.xlsx | Parts Inventory | HW-016
HW-017 | Digital multimeter |  | DT-830/832D family, black | 1 | existing | existing | Receipt screenshot; SKU 3301003003 |  |  | Voltage, resistance and continuity checks | Test probes | Battery powered |  |  |  |  |  |  |  |  |  |  |  |  |  | yes | UNDECIDED | Workbook category: Test equipment | Workbook role: Bench | Evidence wording: Receipt-confirmed; photo not clearly matched | Confidence wording: Medium | Reference-family specifications (not measured): Basic handheld DMM; exact ranges, fuse and safety category depend on actual variant | Software need (not implementation proof): None | Read the exact unit manual. Do not rely on unverified CAT markings for mains work. | Receipt confirms purchase; physical receipt is unresolved because no photo is clearly matched. | Zi-E_Hardware_Master_Inventory.xlsx | Parts Inventory | HW-017
HW-018 | Electrolytic capacitor |  | 10 µF, 35 V | 5 | received | existing | SKU 2021101331 | IMG_0412–IMG_0415 |  | Decoupling/filtering | Through-hole | ≤35 V with design margin |  |  |  |  |  |  |  |  |  |  |  |  |  | yes | UNDECIDED | Workbook category: Capacitor | Workbook role: Primary | Evidence wording: Photo + receipt confirmed | Confidence wording: High | Reference-family specifications (not measured): 10 µF capacitance; 35 V maximum rated voltage; polarized | Software need (not implementation proof): None | Observe polarity and derate voltage. ESR/tolerance unknown. | Zi-E_Hardware_Master_Inventory.xlsx | Parts Inventory | HW-018
HW-019 | Electrolytic capacitor |  | 1000 µF, 10 V, TAICON marking | 5 | received | existing | SKU 2021101139 | IMG_0412–IMG_0415 |  | Bulk power filtering | Through-hole | ≤10 V with design margin |  |  |  |  |  |  |  |  |  |  |  |  |  | yes | UNDECIDED | Workbook category: Capacitor | Workbook role: Primary | Evidence wording: Photo + receipt confirmed | Confidence wording: High | Reference-family specifications (not measured): 1000 µF; 10 V maximum rated voltage; polarized | Software need (not implementation proof): None | Observe polarity; keep well below 10 V. ESR/temperature series unknown. | Zi-E_Hardware_Master_Inventory.xlsx | Parts Inventory | HW-019
HW-020 | Polyester film capacitor |  | 100 nF, 100 V, 5% | 5 | received | existing | SKU 2021006226 | IMG_0391–IMG_0394 |  | Signal filtering/decoupling | Through-hole | ≤100 V with design margin |  |  |  |  |  |  |  |  |  |  |  |  |  | yes | UNDECIDED | Workbook category: Capacitor | Workbook role: Primary | Evidence wording: Photo + receipt confirmed | Confidence wording: High | Reference-family specifications (not measured): 0.1 µF; 100 V; ±5%; non-polarized | Software need (not implementation proof): None | Check lead spacing before PCB/perfboard layout. | Zi-E_Hardware_Master_Inventory.xlsx | Parts Inventory | HW-020
HW-021 | Ceramic disc capacitor |  | 100 nF, marking 104 | 20 | received | existing | SKU 2021005001 | IMG_0408–IMG_0411 |  | Local decoupling | Through-hole | Voltage rating TO VERIFY |  |  |  |  |  |  |  |  |  |  |  |  |  | yes | UNDECIDED | Workbook category: Capacitor | Workbook role: Primary | Evidence wording: Photo + receipt confirmed | Confidence wording: High | Reference-family specifications (not measured): 0.1 µF nominal; voltage rating and dielectric not shown | Software need (not implementation proof): None | Do not infer voltage rating from “104”; it encodes capacitance only. | Zi-E_Hardware_Master_Inventory.xlsx | Parts Inventory | HW-021
HW-022 | Self-locking pushbutton |  | Red, round, 12 × 12 mm | 5 | received | existing | SKU 2181002080 | Photo set |  | Power/mode controls | Mechanical contacts | Rating TO VERIFY |  |  |  |  |  |  |  |  |  |  |  |  |  | yes | UNDECIDED | Workbook category: Switch | Workbook role: Primary | Evidence wording: Photo + receipt confirmed | Confidence wording: High | Reference-family specifications (not measured): Latching/self-locking action per seller; contact rating not verified | Software need (not implementation proof): None | Measure continuity to identify pins and states before wiring. | Zi-E_Hardware_Master_Inventory.xlsx | Parts Inventory | HW-022
HW-023 | Slide switch |  | SK12D07, 3-pin, two-position | 5 | received | existing | SKU 2181001033 | IMG_0412–IMG_0415 |  | Mode/power selection | Mechanical contacts | Rating TO VERIFY |  |  |  |  |  |  |  |  |  |  |  |  |  | yes | UNDECIDED | Workbook category: Switch | Workbook role: Primary | Evidence wording: Photo + receipt confirmed | Confidence wording: High | Reference-family specifications (not measured): SPDT-style 3-pin, two-position form; electrical rating not verified | Software need (not implementation proof): None | Confirm center/common pin with multimeter. | Zi-E_Hardware_Master_Inventory.xlsx | Parts Inventory | HW-023
HW-024 | Crimp terminal contacts |  | 2510 contacts | 50 | received | existing | SKU 2171001057 | IMG_0416–IMG_0418 |  | Wire harness construction | Crimp | Passive |  |  |  |  |  |  |  |  |  |  |  |  |  | yes | UNDECIDED | Workbook category: Connector | Workbook role: Primary | Evidence wording: Photo + receipt confirmed | Confidence wording: Medium | Reference-family specifications (not measured): Seller family “2510”; wire gauge, plating and mating series not confirmed | Software need (not implementation proof): None | Use the correct crimp tool; perform pull-test on first samples. | Zi-E_Hardware_Master_Inventory.xlsx | Parts Inventory | HW-024
HW-025 | Female connector housing |  | EI type, 3-pin | 5 | received | existing | SKU 2171001073 | IMG_0416–IMG_0418 |  | Wire harness construction | Crimp housing | Passive |  |  |  |  |  |  |  |  |  |  |  |  |  | yes | UNDECIDED | Workbook category: Connector | Workbook role: Primary | Evidence wording: Photo + receipt confirmed | Confidence wording: Medium | Reference-family specifications (not measured): 3 positions; pitch and mating header require measurement | Software need (not implementation proof): None | Confirm the ordered contacts actually latch and mate correctly. | Zi-E_Hardware_Master_Inventory.xlsx | Parts Inventory | HW-025
HW-026 | Right-angle connector/housing |  | XH family, 2-pin | 10 | received | existing | SKU 2171001011 | IMG_0416–IMG_0418 |  | Power/signal harness | Through-hole / housing | Passive |  |  |  |  |  |  |  |  |  |  |  |  |  | yes | UNDECIDED | Workbook category: Connector | Workbook role: Primary | Evidence wording: Photo + receipt confirmed | Confidence wording: Medium | Reference-family specifications (not measured): 2 positions; commonly 2.50 mm family but clones vary | Software need (not implementation proof): None | Measure pitch and identify whether item is header or housing. | Zi-E_Hardware_Master_Inventory.xlsx | Parts Inventory | HW-026
HW-027 | Right-angle connector/housing |  | XH family, 3-pin | 10 | received | existing | SKU 2171001017 | IMG_0416–IMG_0418 |  | Power/signal harness | Through-hole / housing | Passive |  |  |  |  |  |  |  |  |  |  |  |  |  | yes | UNDECIDED | Workbook category: Connector | Workbook role: Primary | Evidence wording: Photo + receipt confirmed | Confidence wording: Medium | Reference-family specifications (not measured): 3 positions; commonly 2.50 mm family but clones vary | Software need (not implementation proof): None | Measure pitch and identify whether item is header or housing. | Zi-E_Hardware_Master_Inventory.xlsx | Parts Inventory | HW-027
HW-028 | Straight connector/housing |  | XH family, 4-pin | 12 | received | existing | SKU 2171001031 | IMG_0416–IMG_0418 |  | Power/signal harness | Through-hole / housing | Passive |  |  |  |  |  |  |  |  |  |  |  |  |  | yes | UNDECIDED | Workbook category: Connector | Workbook role: Primary | Evidence wording: Photo + receipt confirmed | Confidence wording: Medium | Reference-family specifications (not measured): 4 positions; commonly 2.50 mm family but clones vary | Software need (not implementation proof): None | Measure pitch and identify whether item is header or housing. | Zi-E_Hardware_Master_Inventory.xlsx | Parts Inventory | HW-028
HW-029 | Screw terminal block |  | KF350, 2-pin, green | 5 | received | existing | SKU 2171012009 | Photo set |  | Detachable field wiring | Screw terminal / through-hole | Rating TO VERIFY |  |  |  |  |  |  |  |  |  |  |  |  |  | yes | UNDECIDED | Workbook category: Connector | Workbook role: Primary | Evidence wording: Photo + receipt confirmed | Confidence wording: Medium | Reference-family specifications (not measured): 2 positions; nominal family pitch likely 3.50 mm, verify actual part | Software need (not implementation proof): None | Verify pitch, current rating and conductor size. | Zi-E_Hardware_Master_Inventory.xlsx | Parts Inventory | HW-029
HW-030 | Screw terminal block |  | KF128, 3-pin, green | 5 | received | existing | SKU 2171012021 | Photo set |  | Power/signal termination | Screw terminal / through-hole | Rating TO VERIFY |  |  |  |  |  |  |  |  |  |  |  |  |  | yes | UNDECIDED | Workbook category: Connector | Workbook role: Primary | Evidence wording: Photo + receipt confirmed | Confidence wording: Medium | Reference-family specifications (not measured): 3 positions; pitch and rating vary by clone | Software need (not implementation proof): None | Verify pitch, current rating and conductor size. | Zi-E_Hardware_Master_Inventory.xlsx | Parts Inventory | HW-030
HW-031 | Heat-shrink tubing assortment |  | 164-piece multicolor kit | 1 | received | existing |  | IMG_0388–IMG_0390 |  | Harness insulation and strain relief | Mechanical insulation | Passive |  |  |  |  |  |  |  |  |  |  |  |  |  | yes | UNDECIDED | Workbook category: Mechanical | Workbook role: Primary | Evidence wording: Photo-confirmed | Confidence wording: High | Reference-family specifications (not measured): 1 mm×40 (60); 2 mm×40 (30); 3 mm×40 (20); 4 mm×40 (16); 6 mm×40 (12); 8 mm×80 (10); 10 mm×80 (8); 14 mm×80 (8) | Software need (not implementation proof): None | Choose size before shrinking; shrink ratio and temperature are not printed/verified. | Zi-E_Hardware_Master_Inventory.xlsx | Parts Inventory | HW-031

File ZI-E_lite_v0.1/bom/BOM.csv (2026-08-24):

Category | Part | Qty | Stage | Notes
Main integrated board | Waveshare ESP32-S3-Touch-LCD-3.5B | 1 | BUY AFTER BODY/SOFTWARE PLAN | 3.5in touch + ESP32-S3 + audio + IMU + RTC + PMIC
Camera | OV5640 DVP module compatible with board | 1 | BUY WITH/AFTER MAIN BOARD | Bundle camera preferred for lowest integration risk
Speaker | 6 ohm 1 W speaker (included) | 1 | INCLUDED | Use board speaker header
Emotion LED | 5mm diffused common-cathode RGB LED | 1 | CHEAP | 3x 330R series resistors
RGB resistors | 330 ohm 1/4W | 3 | CHEAP | Tune later if needed
Battery | Protected 1S 3.7V LiPo 4000mAh, <=95x55x12mm | 1 | LATER | Optional; USB-C first
Shell | 5052-H32 aluminum sheet 1.5mm | ~0.25 m2 | FABRICATE | 1.3mm acceptable fallback
Stationary base | Aluminum sheet 2.0mm 170x120mm | 1 | FABRICATE | 4 rubber feet
Rear service hardware | M3 screws + rivnuts/nuts + angle tabs | set | FABRICATE | Body and head rear panels removable
Board mounts | M2 standoffs + insulating washers | 4 | AFTER BOARD | 72 x 48.5mm board hole spacing
RF window | Polycarbonate/ABS/acrylic 35x20mm | 1 | FABRICATE | Required in aluminum head
Cable protection | Rubber grommet / edge trim / heatshrink | set | FABRICATE | No wire on raw aluminum edges
Feet | Rubber feet | 4 | CHEAP | Stationary first build

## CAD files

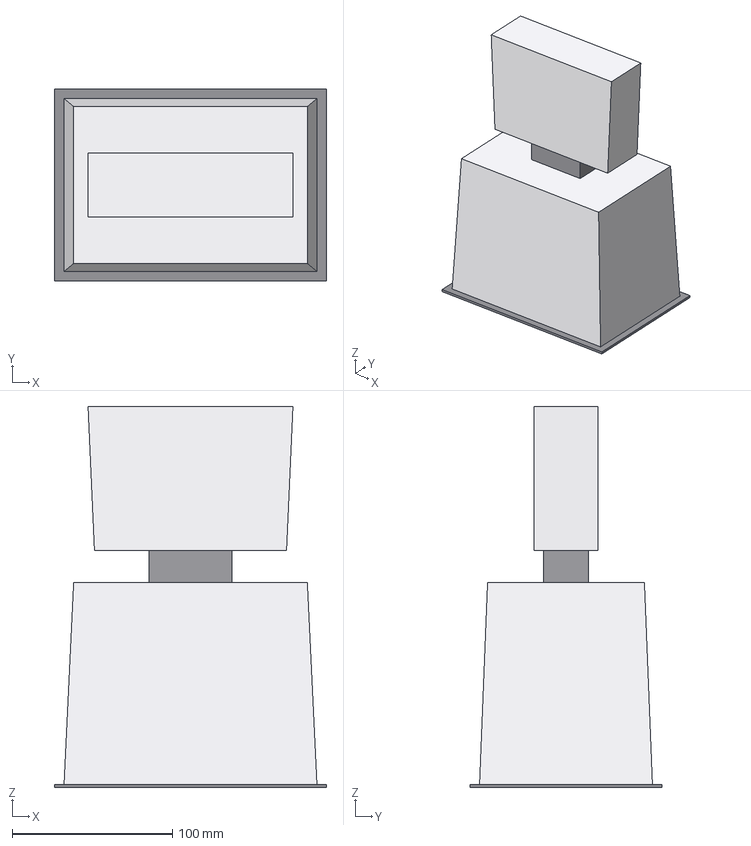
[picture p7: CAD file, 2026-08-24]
ZI-E_lite_v0.1/cad/ZI-E_Lite_v0.1_ASSEMBLY.step
170.0 x 120.0 x 238.0 mm
stationary_base
body_shell
fixed_neck
head_shell
display_board_envelope

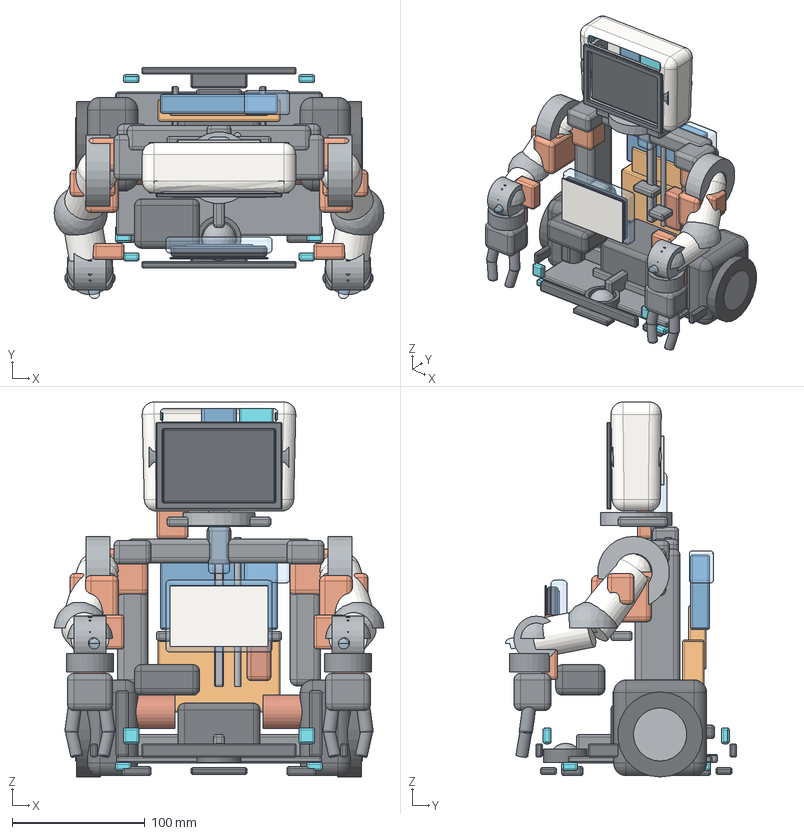
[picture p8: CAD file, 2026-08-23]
mechanical/cad/current/cad/ZI-E_v0_3_CUTAWAY.step
248.0 x 173.9 x 282.0 mm
lower_chassis
shutdown_foot_0
shutdown_foot_1
shutdown_foot_2
shutdown_foot_3
rear_bridge
shoulder_tower_-1
shoulder_tower_1
battery_cassette
M35A_cell_1
M35A_cell_2
M35A_cell_3
M35A_cell_4
M35A_cell_5
M35A_cell_6
battery_rail_0
battery_rail_1
battery_rail_2
main_multimedia_board_env
safety_motion_board_env
power_distribution_board_env
esp32_antenna_keepout
speaker_chamber
PUI_AS04004PO_env
belly_deadfront_window
belly_matrix_baffle
IS31FL3741_13x9_proto_env
belly_matrix_future_keepout
cliff_sensor_1
cliff_sensor_2
cliff_sensor_3
cliff_sensor_4
proximity_sensor_1
proximity_sensor_2
proximity_sensor_3
proximity_sensor_4
bumper_segment_1
bumper_segment_2
bumper_segment_3
bumper_segment_4
ball_caster_ball
ball_caster_cartridge
anti_tip_skid_0
anti_tip_skid_1
wheel_-1_tire
wheel_-1_hub
wheel_-1_axle
wheel_-1_motor
wheel_-1_pulley1
wheel_-1_pulley2
wheel_-1_cover
wheel_-1_fairing
wheel_-1_hinge
wheel_-1_stop
wheel_-1_lock
wheel_1_tire
wheel_1_hub
wheel_1_axle
wheel_1_motor
wheel_1_pulley1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

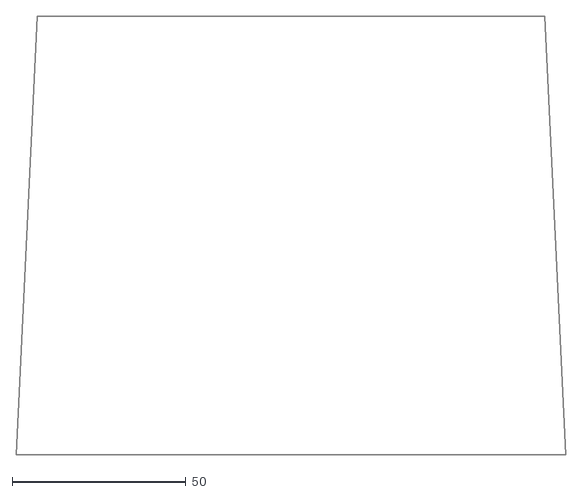
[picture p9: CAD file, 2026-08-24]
ZI-E_lite_v0.1/templates/dxf/BODY_REAR.dxf
158.0 x 126.0

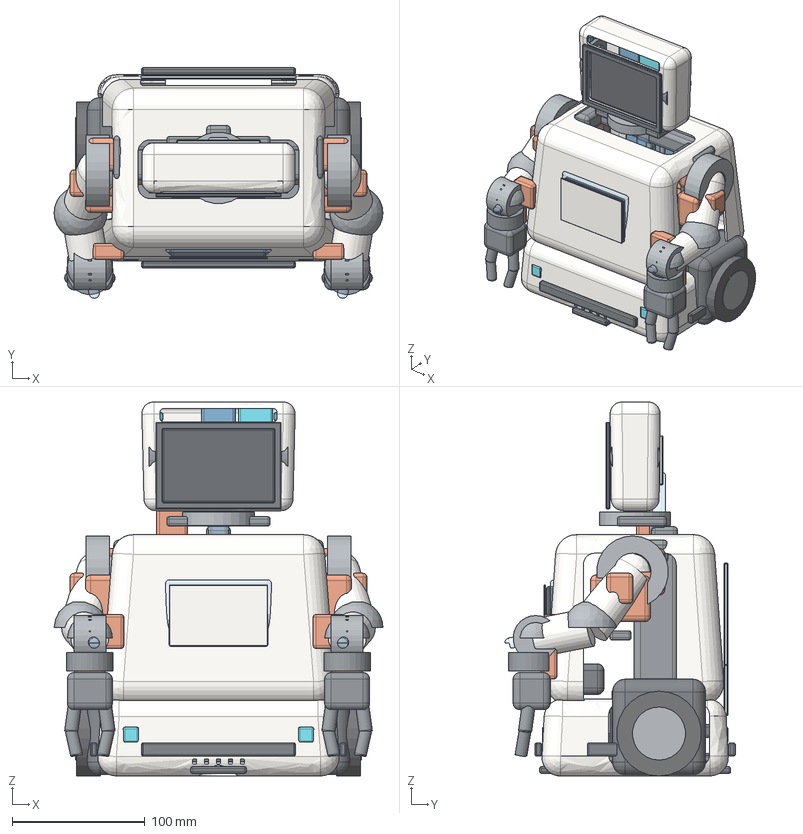
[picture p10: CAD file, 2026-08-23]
mechanical/cad/current/cad/ZI-E_v0_3_ACTIVE.step
248.0 x 173.9 x 282.0 mm
base_shell
torso_shell
rear_service_cover
battery_door
lower_chassis
shutdown_foot_0
shutdown_foot_1
shutdown_foot_2
shutdown_foot_3
rear_bridge
shoulder_tower_-1
shoulder_tower_1
battery_cassette
M35A_cell_1
M35A_cell_2
M35A_cell_3
M35A_cell_4
M35A_cell_5
M35A_cell_6
battery_rail_0
battery_rail_1
battery_rail_2
main_multimedia_board_env
safety_motion_board_env
power_distribution_board_env
esp32_antenna_keepout
speaker_chamber
PUI_AS04004PO_env
belly_deadfront_window
belly_matrix_baffle
IS31FL3741_13x9_proto_env
belly_matrix_future_keepout
cliff_sensor_1
cliff_sensor_2
cliff_sensor_3
cliff_sensor_4
proximity_sensor_1
proximity_sensor_2
proximity_sensor_3
proximity_sensor_4
bumper_segment_1
bumper_segment_2
bumper_segment_3
bumper_segment_4
ball_caster_ball
ball_caster_cartridge
anti_tip_skid_0
anti_tip_skid_1
wheel_-1_tire
wheel_-1_hub
wheel_-1_axle
wheel_-1_motor
wheel_-1_pulley1
wheel_-1_pulley2
wheel_-1_cover
wheel_-1_fairing
wheel_-1_hinge
wheel_-1_stop
wheel_-1_lock
wheel_1_tire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

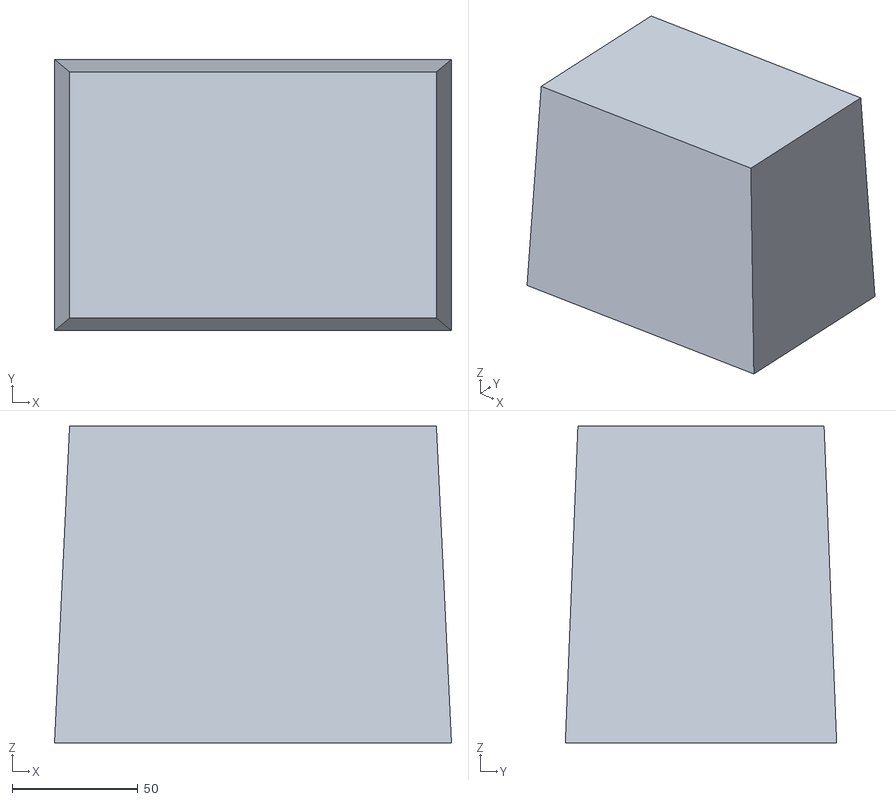
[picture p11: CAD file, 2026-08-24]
ZI-E_lite_v0.1/cad/body_shell.stl
158.0 x 108.0 x 126.0

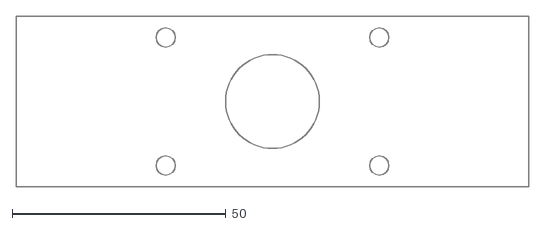
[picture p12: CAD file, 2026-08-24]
ZI-E_lite_v0.1/templates/dxf/HEAD_BOTTOM.dxf
120.0 x 40.0

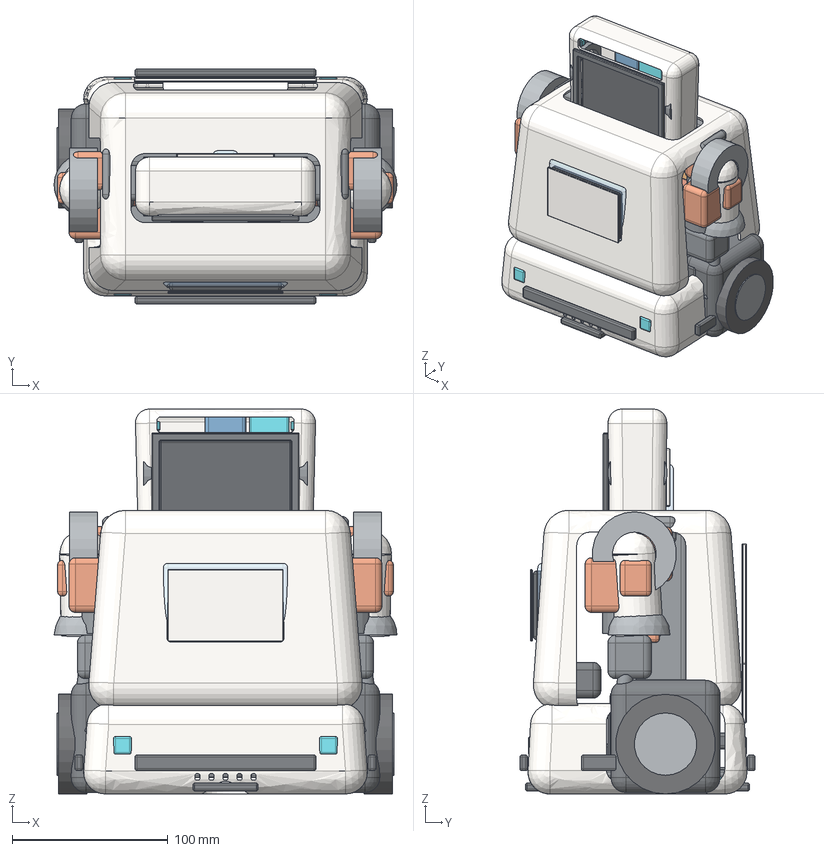
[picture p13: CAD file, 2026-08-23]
mechanical/cad/current/cad/ZI-E_v0_3_SLEEP.step
220.0 x 151.0 x 247.0 mm
base_shell
torso_shell
rear_service_cover
battery_door
lower_chassis
shutdown_foot_0
shutdown_foot_1
shutdown_foot_2
shutdown_foot_3
rear_bridge
shoulder_tower_-1
shoulder_tower_1
battery_cassette
M35A_cell_1
M35A_cell_2
M35A_cell_3
M35A_cell_4
M35A_cell_5
M35A_cell_6
battery_rail_0
battery_rail_1
battery_rail_2
main_multimedia_board_env
safety_motion_board_env
power_distribution_board_env
esp32_antenna_keepout
speaker_chamber
PUI_AS04004PO_env
belly_deadfront_window
belly_matrix_baffle
IS31FL3741_13x9_proto_env
belly_matrix_future_keepout
cliff_sensor_1
cliff_sensor_2
cliff_sensor_3
cliff_sensor_4
proximity_sensor_1
proximity_sensor_2
proximity_sensor_3
proximity_sensor_4
bumper_segment_1
bumper_segment_2
bumper_segment_3
bumper_segment_4
ball_caster_ball
ball_caster_cartridge
anti_tip_skid_0
anti_tip_skid_1
wheel_-1_tire
wheel_-1_hub
wheel_-1_axle
wheel_-1_motor
wheel_-1_pulley1
wheel_-1_pulley2
wheel_-1_cover
wheel_-1_fairing
wheel_-1_hinge
wheel_-1_stop
wheel_-1_lock
wheel_1_tire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

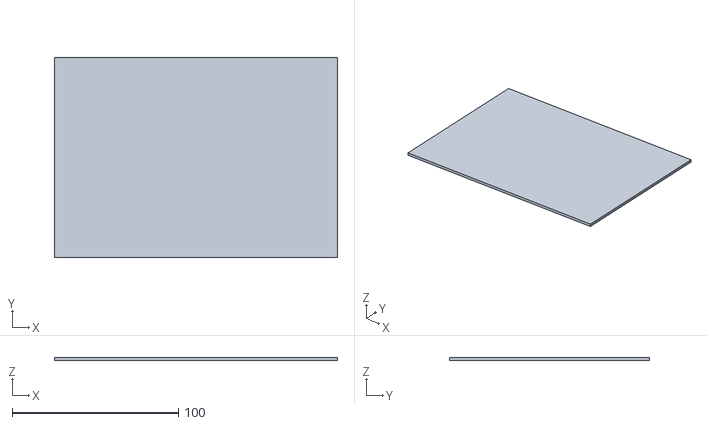
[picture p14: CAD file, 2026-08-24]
ZI-E_lite_v0.1/cad/stationary_base.stl
170.0 x 120.0 x 2.00

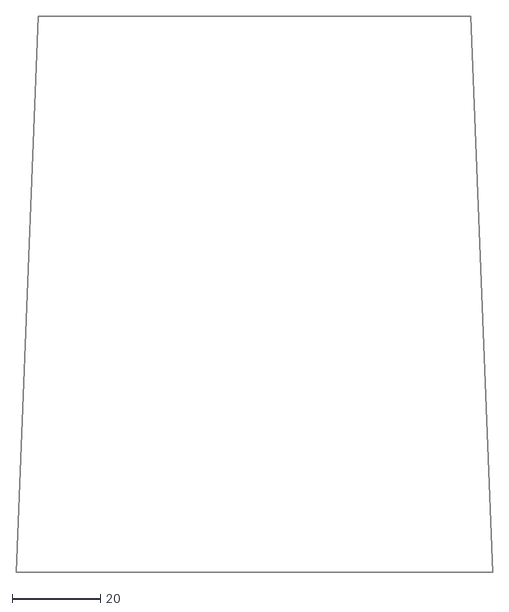
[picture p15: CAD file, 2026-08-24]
ZI-E_lite_v0.1/templates/dxf/BODY_LEFT_SIDE.dxf
108.0 x 126.0

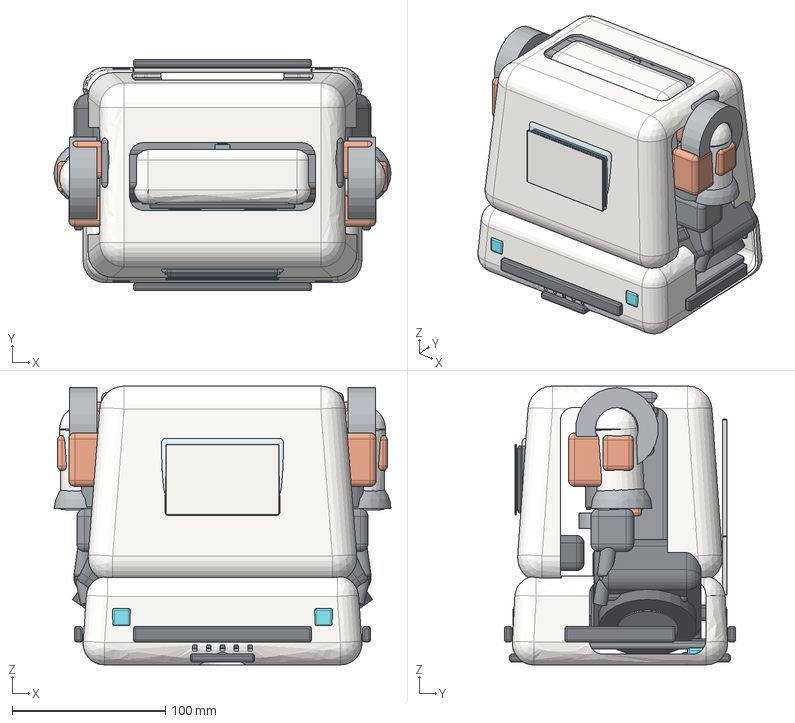
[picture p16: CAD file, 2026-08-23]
mechanical/cad/current/cad/ZI-E_v0_3_SHUTDOWN.step
220.0 x 151.0 x 182.0 mm
base_shell
torso_shell
rear_service_cover
battery_door
lower_chassis
shutdown_foot_0
shutdown_foot_1
shutdown_foot_2
shutdown_foot_3
rear_bridge
shoulder_tower_-1
shoulder_tower_1
battery_cassette
M35A_cell_1
M35A_cell_2
M35A_cell_3
M35A_cell_4
M35A_cell_5
M35A_cell_6
battery_rail_0
battery_rail_1
battery_rail_2
main_multimedia_board_env
safety_motion_board_env
power_distribution_board_env
esp32_antenna_keepout
speaker_chamber
PUI_AS04004PO_env
belly_deadfront_window
belly_matrix_baffle
IS31FL3741_13x9_proto_env
belly_matrix_future_keepout
cliff_sensor_1
cliff_sensor_2
cliff_sensor_3
cliff_sensor_4
proximity_sensor_1
proximity_sensor_2
proximity_sensor_3
proximity_sensor_4
bumper_segment_1
bumper_segment_2
bumper_segment_3
bumper_segment_4
ball_caster_ball
ball_caster_cartridge
anti_tip_skid_0
anti_tip_skid_1
wheel_-1_tire
wheel_-1_hub
wheel_-1_axle
wheel_-1_motor
wheel_-1_pulley1
wheel_-1_pulley2
wheel_-1_cover
wheel_-1_fairing
wheel_-1_hinge
wheel_-1_stop
wheel_-1_lock
wheel_1_tire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

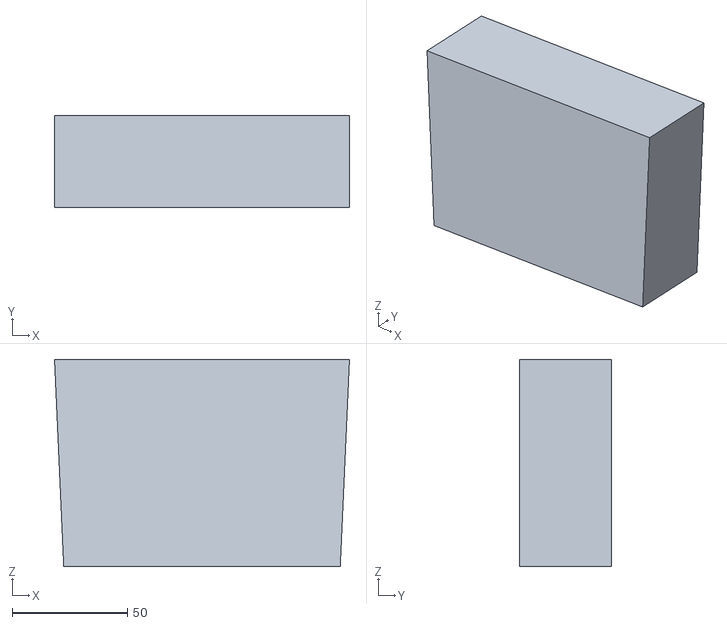
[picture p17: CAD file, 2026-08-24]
ZI-E_lite_v0.1/cad/head_shell.stl
128.0 x 40.0 x 90.0

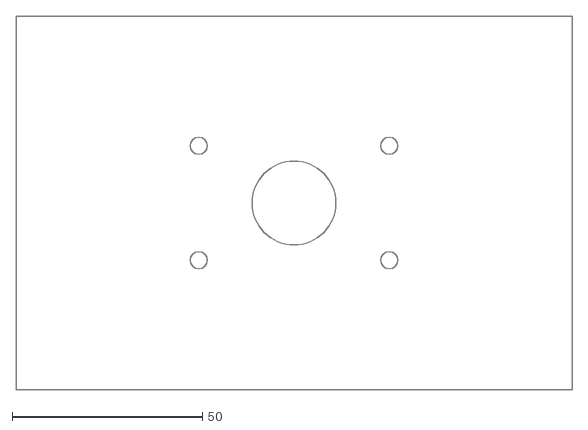
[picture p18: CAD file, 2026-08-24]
ZI-E_lite_v0.1/templates/dxf/BODY_TOP.dxf
146.0 x 98.0

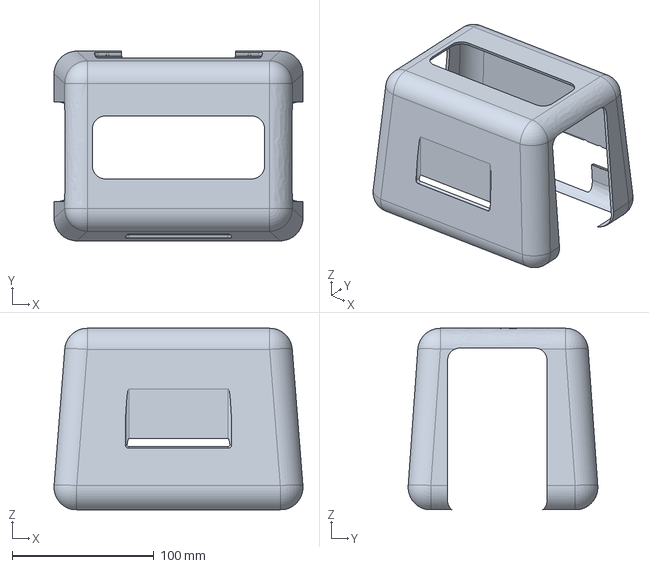
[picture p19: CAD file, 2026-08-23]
mechanical/cad/current/cad/torso_shell.step
175.4 x 133.7 x 127.9 mm

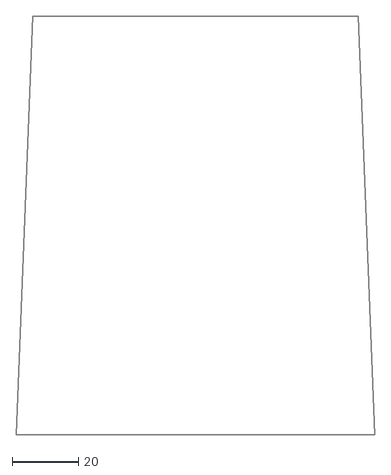
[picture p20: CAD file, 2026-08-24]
ZI-E_lite_v0.1/templates/dxf/BODY_RIGHT_SIDE.dxf
108.0 x 126.0

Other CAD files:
mechanical/cad/current/cad/belly_deadfront_window_REFERENCE.step
ZI-E_lite_v0.1/templates/dxf/HEAD_RIGHT_SIDE.dxf
mechanical/cad/current/cad/belly_matrix_baffle.step
ZI-E_lite_v0.1/templates/dxf/STATIONARY_BASE.dxf
mechanical/cad/archive/v0.1/ZI-E_CAD_v0_1.scad
ZI-E_lite_v0.1/templates/dxf/BATTERY_CARRIER.dxf
ZI-E_lite_v0.1/templates/dxf/BOARD_CARRIER.dxf
ZI-E_lite_v0.1/templates/dxf/BODY_BOTTOM.dxf
ZI-E_lite_v0.1/templates/dxf/BODY_FRONT.dxf
ZI-E_lite_v0.1/templates/dxf/HEAD_FRONT.dxf
ZI-E_lite_v0.1/templates/dxf/HEAD_LEFT_SIDE.dxf
ZI-E_lite_v0.1/templates/dxf/HEAD_REAR.dxf
ZI-E_lite_v0.1/templates/dxf/HEAD_TOP.dxf
legacy/exports/ZI-E_lite_v0.1/templates/dxf/BATTERY_CARRIER.dxf
legacy/exports/ZI-E_lite_v0.1/templates/dxf/BOARD_CARRIER.dxf
legacy/exports/ZI-E_lite_v0.1/templates/dxf/BODY_BOTTOM.dxf
legacy/exports/ZI-E_lite_v0.1/templates/dxf/BODY_FRONT.dxf
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

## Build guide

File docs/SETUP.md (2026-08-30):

# ZI-E V1 Setup

Run `scripts/setup_zi-e.ps1` in PowerShell. It creates `.venv`, installs pinned
dependencies, and creates a git-ignored `.env` with a random bearer token. Configure
`ZIE_HERMES_COMMAND=hermes`; Hermes 0.20.6 must already be authenticated separately.

Optionally enable Camofox with `ZIE_CAMOFOX_ENABLED=true`; the launcher accepts only
the fixed executable name `camofox`, with no shell expression or caller arguments. Start with
`scripts/start_zi-e.ps1`; it starts enabled dependencies and the server, waits for
authenticated health, then opens the HUD. Validate with `health_zi-e.ps1` and stop
with `stop_zi-e.ps1`. The short legacy script names remain wrappers.

For the complete host/ESP32/STM32 preparation flow, start with
`scripts/toolchain-doctor.ps1`, then use the fixed host actions in
`scripts/firmware-workflow.ps1`. Target actions require a reviewed board profile and
explicit device identity; see `DEVELOPMENT_PIPELINE_READINESS.md`. Vendor SDKs remain
outside this repository.

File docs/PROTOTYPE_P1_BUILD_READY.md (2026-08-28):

# Prototype Phase 1 Build-Ready Package — 2026-08-28

The Control Center V1 exposes this package as honest P1/CAD status, non-persistent
inventory preview, and a commissioning checklist. It does not make CAD data,
inventory rows, simulator output, or software tests satisfy a physical gate.

Status: process and worksheets are ready; execution is blocked on received hardware
and operator-confirmed measurements. Every physical value not backed by received-part
evidence is `VERIFY_ON_ARRIVAL`.

Canonical companion artifacts for this package:

- `HARDWARE_SOURCE_OF_TRUTH_RECONCILIATION.md`
- `PURCHASED_PARTS_INTAKE_SCHEMA.md` and its empty CSV template
- `P1_CAD_FREEZE_CANDIDATE.md`
- `P1_ASSEMBLY_ELECTRICAL_BRINGUP_PACKAGE.md`
- `P1_PHYSICAL_VERIFICATION_WORKSHEET.md`
- `PHASE2B2_INPUT_GATE.md`

These documents supersede generic rows below when more precise, without converting
CAD/listing assumptions into physical facts.

## P1 scope and controller map

P1 is a supervised bench prototype: power domains, ESP32-S3 multimedia/presence,
STM32 local safety/motion ownership, sensors, one actuator at a time, communication,
safe stop, and fault containment. It excludes autonomous motion and production claims.

| Owner | Responsibility | Forbidden boundary |
|---|---|---|
| ESP32-S3/host | multimedia, presence, providers, presentation, semantic intents, diagnostics | raw actuator or protected-safety control |
| STM32 | local interlocks, actuator gating, actual-state confirmation, safe stop | AI/provider authority |
| Operator | physical inspection, instrument readings, gate confirmation | replacing evidence with a software flag |
| VirtualRobot | software integration and fault simulation | claiming physical verification |

## BOM and arrival ledger

Use one row per exact purchasable part. Do not infer status from CAD presence.

| Item / exact model | Qty | Status: existing / required / ordered / substitute candidate | Evidence | Arrival inspection | Result |
|---|---:|---|---|---|---|
| ESP32-S3 multimedia controller | TBD | required | purchase record | `VERIFY_ON_ARRIVAL` exact module/revision/voltage/interfaces | pending |
| STM32 safety controller | TBD | required | purchase record | `VERIFY_ON_ARRIVAL` exact MCU/board/revision | pending |
| Display/camera/audio parts | TBD | required | component matrix | `VERIFY_ON_ARRIVAL` connector, dimensions, controller IC | pending |
| Sensors and actuator samples | TBD | required | component matrix | `VERIFY_ON_ARRIVAL` model, class, voltage, identity | pending |
| Power/BMS/protection parts | TBD | required | approved purchase decision required | `VERIFY_ON_ARRIVAL` ratings and provenance | pending |
| Fasteners/spacers/brackets | TBD | required | assembly drawing/cut list | `VERIFY_ON_ARRIVAL` thread, length, material, clearance | pending |

Substitutes require a documented interface, voltage, mechanical, thermal, safety, and
availability comparison plus Product Owner approval before use.

## Assembly order and mechanical checklist

1. Inventory and photograph labels; quarantine mismatches.
2. Measure parts before modifying CAD or brackets.
3. Assemble non-powered structure, service access, hard stops, guards, and strain
   relief before electronics.
4. Install protected power distribution with loads disconnected.
5. Install controllers and logic-only interfaces.
6. Bring up sensors, then individual actuator branches, then constrained integration.

Check fastener thread/length, washers, locking method, captive access, spacer height,
bracket flatness, sharp edges, insulation from conductors, bearing support, hard-stop
load path, tool clearance, and service-removal access. All dimensions are
`VERIFY_ON_ARRIVAL`.

## Power and connector architecture

High level only: source -> fuse/current limit -> protected distribution -> separately
switchable safety/motion, logic, and non-safety multimedia branches. STM32/local
safety must retain the means to remove actuator authority independently. The belly
matrix and cosmetic loads fail dark and cannot share a safety-critical single point of
failure. Final wire gauge, fuse, shunt, FET, connector, transient, and thermal values
are `VERIFY_ON_ARRIVAL` after measured load waveforms.

| Interface | End A / owner | End B / owner | Semantic purpose | Physical details |
|---|---|---|---|---|
| ESP32–STM32 | ESP32 host | STM32 safety | bounded semantic command/state/liveness | CAN/TWAI details `VERIFY_ON_ARRIVAL`; Phase 2B2 waiting |
| Display/camera/audio | ESP32 | multimedia devices | presentation/perception | pins/connectors `VERIFY_ON_ARRIVAL` |
| Safety sensors | STM32 | cliff/bumper/power sensors | local interlock evidence | pins/levels `VERIFY_ON_ARRIVAL` |
| Actuator branches | STM32-authorized interface | one bounded actuator/domain | commissioned motion only | bus/IDs/baud/voltage `VERIFY_ON_ARRIVAL` |

Preliminary pin worksheet fields: signal, semantic owner, board pin, direction,
voltage, pull state, boot behavior, connector/cavity, protection, cable length,
source drawing, measured evidence, reviewer. Every populated physical pin remains
`VERIFY_ON_ARRIVAL` until continuity and board documentation agree.

## Flashing checklists

ESP32-S3: verify exact board and USB mode; obtain authoritative board instructions;
record toolchain/firmware digest; disconnect actuator power; flash a logic-only image;
capture boot log; verify reset/recovery path. Port, boot pins, and image target are
`VERIFY_ON_ARRIVAL`.

STM32: verify exact MCU/debug connector/voltage; connect current-limited logic power;
preserve recovery/debug access; flash a non-motion commissioning image; record
toolchain/image digest and option-byte state; verify reset/watchdog behavior. Probe
pinout and board settings are `VERIFY_ON_ARRIVAL`.

## Bench bring-up and first power

1. Unpowered continuity, polarity, isolation, fastener, cable, and foreign-object
   inspection; actuator branches disconnected.
2. Current-limited source at the verified logic requirement; operator at disconnect;
   record idle/inrush voltage/current/temperature.
3. Verify controller identity, logs, watchdog, and safe outputs.
4. Verify each sensor independently, including plausible change and disconnected/stuck
   faults.
5. Keep actuator power disabled while discovering exact model/voltage/bus/baud/ID.
6. Enable one restrained actuator at low configured limits; verify direction, zero,
   range, feedback, stop, and power removal before the next actuator.
7. Test constrained multi-subsystem behavior only after every prior gate passes.

Smoke tests: controller boot/recovery, state/event generation, sensor plausible/fault
states, display/audio fail-safe degradation, provider mocks, command accepted versus
executed distinction, watchdog, safe-stop input, and loss-of-link behavior.

## Commissioning state machine

`unpowered -> inspection_complete -> logic_power_only -> controller_connected ->
sensors_verified -> actuator_power_disabled -> individual_actuator_test ->
constrained_motion_test -> safety_stop_verified -> bench_integrated ->
ready_for_supervised_prototype`

Each transition requires recorded operator/physical evidence plus the relevant test;
simulation success is a separate field. A failed gate removes actuator authority and
returns to `actuator_power_disabled` or `unpowered` as the failure requires. Individual
tests have explicit time/current/range bounds derived from verified hardware. No
software flag can assert a physical transition by itself. Autonomous motion remains
prohibited throughout P1.

## Test and evidence worksheets

- Sensors: identity, supply, raw/plausible response, limit cases, stale/disconnect,
  environmental matrix, pass/fail, operator/time.
- Actuators: model/voltage, bus/baud/ID, direction, zero/range, end sensors, plausible
  feedback, current/temperature, bounded duration, stop response.
- Safe stop: trigger type, starting condition, command rejection, physical power/state,
  measured stop timing (`VERIFY_ON_ARRIVAL`), restart authority remains absent.
- Measurements on arrival: exact revision, dimensions, mass/COM where relevant,
  connector/pinout, voltage/current, thermal observation, photo/datasheet provenance.
- Cable/strain relief: bend radius, moving loop, edge protection, service loop,
  connector retention, flex cycles, separation from noisy power.
- Fault containment: unplug/open/short where safely instrumented, stuck sensor, bus
  loss, controller reset, optional-device failure, branch fuse/current limit, thermal
  and e-stop/disconnect response.

## CAD readiness

The current parameterized v0.3 CAD and STEP/STL exports support fit coupons, envelope
review, and bench fixtures. The architecture, state variants, service zones, protected
controller split, and parametric workflow are usable. Physical clearances, display and
sensor geometry, head/arm mass and COM, actuator ratios, cable loops, battery/power
hardware, final shell surfaces, and received-part-dependent dimensions remain
`VERIFY_ON_ARRIVAL`. Existing mass, torque, stability, and thermal figures are model
outputs/estimates, not measurements. No geometry is fabricated by this stage.

## Go/no-go gates

No supervised constrained motion until identity, voltage class, bus/baud, direction,
zero/range, end-state sensors, plausible feedback, current limiting, restraint, and
manual stop pass. No integrated bench state until every required sensor and local
safe-stop path passes. No autonomous motion until a later separately approved hardware
commissioning phase validates physical timing and all safety gates. VirtualRobot,
received-command, or software-ready status is never sufficient.

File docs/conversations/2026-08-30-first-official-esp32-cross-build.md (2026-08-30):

# First official ESP32-S3 cross-build pass — 2026-08-30

The Product Owner requested Zi-E's first official ESP-IDF v6.0.2 ESP32-S3 cross-build
from checkpoint `d71adb253e1fcf8d1f17110f79ede2af8efee35d`, without commit, push, flash,
port discovery, or inferred HW-002 bindings.

The existing target was retained and expanded into a bounded generic Presence Runtime.
No GPIO, I2S, I2C, TWAI, camera, display, codec, motor, or actuator implementation was
added. A fixed workflow performs only clean, target selection, reconfigure, build, and
size. Control Center keeps software, generic-build, verified-board, physical-target,
and flash states separate. Toolchain Doctor separates the launcher from the framework
version and treats pip as optional for the validated uv-managed App environment.

Windows denied the Codex sandbox account execution access to user-installed EIM and
its Python environment, so the official configure/link result was not promoted to PASS.
The exact continuation command in normal PowerShell is:

```powershell
cd 'C:\Users\mohamad alayan\Desktop\Zi-E'
eim run "powershell -ExecutionPolicy Bypass -File .\scripts\build-esp32.ps1"
```

No hardware was flashed or selected. Software-only validation passed.

Follow-up execution exposed a Windows `idf.py` launcher-association quoting defect: the
canonical path was split before ESP-IDF parsed `-B`. The workflow was corrected to call
the official `$IDF_PATH\tools\idf.py` through EIM's Python with an argument array. HW-002
is now physically received/present but remains unverified; the separately bench-tested
spare HW678 / S3-N16R8 board does not establish a final HW-002 board profile.

The corrected normal-PowerShell run then passed clean configuration, ESP32-S3 GCC 15.2
compile, link, bootloader/application generation, and size under ESP-IDF v6.0.2 from
the canonical space-containing path. No junction, flash, port, or hardware access was
used. The application was `0x27350` bytes; IDF reported 160,471 bytes total and DIRAM
at 13.83%. Its IRAM 100% row describes only the dedicated 16 KiB slice before shared
D/IRAM, not exhaustion of the full linker region. The upstream 2 MB flash default is
recorded solely as generic build configuration and supplies no HW-002 evidence.

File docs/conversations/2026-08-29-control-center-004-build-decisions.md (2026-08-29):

# Control Center 0.04 build-decision session — 2026-08-29

Work continued from pushed base `214ca2d` without reset, commit, or push. The corrected
scope preserved 0.03 persistence and avoided rebuilding generic inventory machinery.
0.04 adds conservative required-hardware, missing-evidence, WHAT I NEED FROM YOU,
CAD/electrical/driver, ESP32/STM32, first-power, commissioning-prerequisite, and Phase
2B2 reports.

Actual inventory remains authoritative only with user evidence; candidates are never
seeded. Reports have robot authority `NONE`, cannot verify hardware or pass physical
commissioning, and Phase 2B2 remains `WAITING_FOR_VERIFIED_INPUTS`. Documentation now
records 0.03 as committed in `214ca2d`, separates App version from physical evidence
progression, and distinguishes the historical Phase A–I plan from the active workflow.

The shutdown-recovery audit preserved the complete working tree and reviewed the diff
for physical-truth, security, and authority regressions. Full App pytest passed exactly
113 tests, and the fallback runner passed exactly 44 tests with 0 failures. Compileall,
PowerShell parsing, HTML parsing, JavaScript syntax, the canonical 32-column inventory
contract, reconciliation invariants, and `git diff --check` passed. Adversarial checks
confirmed that suggestions cannot create purchased coverage, unreviewed text cannot
advance readiness, verification requires explicit reviewed real evidence, simulation
cannot physically confirm, commissioning remains physical-only, real targets fail
closed, and no raw CAN/GPIO/PWM/motor/actuator authority was added.

Actual purchased inventory remains 0. Phase 2B2 remains
`WAITING_FOR_VERIFIED_INPUTS`; physical commissioning remains NOT DONE. The session
stops uncommitted and unpushed at `READY_TO_COMMIT` on unchanged HEAD `214ca2d`.

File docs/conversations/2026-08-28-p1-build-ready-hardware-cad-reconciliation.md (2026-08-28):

# Prototype P1 build-ready and hardware/CAD reconciliation — 2026-08-28

## Scope

Continued from clean authoritative HEAD `1ef73b7`. Audited current hardware/CAD/BOM,
P1, risk, roadmap, design and mechanical sources without restoring archived choices or
inventing purchased parts/measurements.

## Artifacts

- Canonical hardware/module reconciliation and conflict register.
- Empty Google Sheet/CSV physical inventory intake contract.
- P1 CAD fixed/parametric/measurement-blocked/optional freeze candidate.
- Assembly, fastener, service, wiring, power and first-power package.
- Arrival-day physical verification worksheet and P1 no-go sign-off.
- Condensed Phase 2B2 Classical CAN input gate.
- Updated P1 package, component/CAD pointers, decisions, risks, current state and
  roadmap.

## Safety disposition

No hardware is claimed physically verified. v0.3 CAD numerical results remain model
outputs. Physical commissioning is not done; production drivers/CAN are not started;
autonomous motion remains prohibited. Phase 2B2 remains
`WAITING_FOR_VERIFIED_INPUTS`.

## Validation

- Committed CAD dataset/schema: 39 checks, 38 pass, one restricted.
- Purchased-parts template: header-only, 32 unique required fields.
- Fresh CAD regeneration could not run because CadQuery is not installed. The release
  checksum manifest also disagrees with an untouched STEP file in this checkout, so
  neither regeneration nor full artifact-integrity validation is claimed.
- Independent adversarial review found omitted named alternatives and incomplete BOM
  status representation; both were repaired. It otherwise found no invented facts,
  unsafe authority mapping, premature CAN freeze, or commissioning overclaim.
- Final `git diff --check` is required before handoff. No commit or push was performed.

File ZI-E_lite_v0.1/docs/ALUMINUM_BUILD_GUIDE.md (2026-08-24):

# Aluminum Build Guide

## Material and fabrication strategy
- Preferred: 5052-H32 aluminum, 1.5 mm shell; 2.0 mm stationary base.
- Weld only the structural/cosmetic shell seams. Keep the body rear panel and head rear panel removable with screws.
- Add small internal aluminum-angle tabs/rails for the removable covers.
- Never weld with electronics, camera, speaker or battery installed. Remove all metal chips before installing electronics.

## One-shot fabrication loop
1. Print the 1:1 PDF at **Actual Size / 100%**. Measure the 50 mm calibration line. If it is not exactly 50 mm, stop.
2. Tape the paper to the aluminum and center-punch every marked pilot point.
3. Cut the shell pieces slightly proud if cutting by hand; final-scribe and trim during dry fit. Handmade TIG-welded sheet metal will not hold sub-0.5 mm enclosure tolerances without a jig.
4. Dry-clamp the whole body. Check top/bottom diagonals and symmetry.
5. Tack weld opposite corners in alternating order. Do not run a long continuous bead on one side first; heat distortion will move the shell.
6. Recheck the display opening and removable rear-cover fit after tacking.
7. Finish with short alternating welds/stitches. Let the part cool between sections.
8. Grind cosmetic outside seams only as much as necessary. Keep internal corner material where it adds stiffness.
9. Fit rubber feet and the removable stationary base plate.
10. Install insulating board spacers, foam gasket around the display, RF window, microphone vent foam and speaker only after all metalwork is done.

## Electronics insulation
- Keep at least ~2-3 mm clearance between PCB solder joints and aluminum.
- Use M2 standoffs plus insulating washers or a thin FR4/Kapton barrier where needed.
- No loose wire should be able to rub on a sharp aluminum edge; use grommets and edge trim.

## RF window
The ESP32 antenna must not be fully surrounded by aluminum. Fit a 35 x 20 mm polycarbonate/ABS/acrylic window in the marked rear/right head zone. Keep metal and battery wiring away from that zone. If Wi-Fi/BLE remains weak, use the board IPEX external antenna option.

## Serviceability
The rear body and rear head covers are intentionally not welded. The software prototype will be opened many times. This is a feature, not a cosmetic compromise.

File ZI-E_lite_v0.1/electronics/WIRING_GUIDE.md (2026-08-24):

# ZI-E Lite v0.1 Wiring Guide

## Main board
Waveshare ESP32-S3-Touch-LCD-3.5B. The display, capacitive touch, ESP32-S3R8, 8 MB PSRAM, 16 MB flash, IMU, RTC, microphone, audio codec and power management are already on the board.

## Connections
### 1. Camera
OV5640 module -> board camera FPC connector. Follow the connector orientation shown by Waveshare; do not reverse the flex cable. No breadboard jumper wires are used for the camera bus.

### 2. Speaker
Included 6 ohm / 1 W speaker -> MX1.25 speaker connector on the board. Speaker polarity is not critical for a single speaker. Route the two wires through the fixed neck into the lower body speaker chamber.

### 3. RGB emotion LED
Use a common-cathode diffused RGB LED.
- GPIO39 -> 330 ohm -> R anode
- GPIO40 -> 330 ohm -> G anode
- GPIO41 -> 330 ohm -> B anode
- LED common cathode -> GND
Use PWM; begin with low duty cycle. If a particular LED is too dim, resistor values can be tuned after the optical test. Do not exceed the LED/GPIO current ratings.

Header reference from the board pinout: GPIO39, GPIO40, GPIO41 and multiple GND pins are exposed on the 2.54 mm header.

### 4. Power during software development
Laptop/USB supply -> board USB-C. This is the default for v0.1. Do not add the battery until the software and current draw are known.

### 5. Optional battery later
Protected 1S 3.7 V LiPo -> board MX1.25 battery header. Verify connector polarity with the Waveshare schematic/board marking before plugging it in. Never connect a 2S/3S battery to this connector. Never connect the LiPo to the board 5V pin.

### 6. Optional external antenna
If the closed aluminum head reduces Wi-Fi/BLE range, enable the board's IPEX antenna path using the manufacturer procedure and attach a 2.4 GHz flex antenna behind the non-metallic RF window.

## Cable bundle through the neck
Only these cables need to leave the head in the Lite build:
- 2 speaker wires
- 4 RGB wires (R/G/B/GND) if LED is in body
- 2 battery wires if battery is in body
- optional USB-C extension/cable

Keep the camera FPC entirely inside the head.

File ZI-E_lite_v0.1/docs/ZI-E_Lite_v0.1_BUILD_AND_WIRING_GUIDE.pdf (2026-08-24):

# ZI-E Lite Aluminum v0.1

Software-first stationary prototype - fixed head - no 3D printing

Build objective: finish the AI/face/vision/voice software in a real ZI-E shell before buying the expensive wheel, arm and motorized-head mechanics.

Nominal size: body 126 mm high, 158->146 mm wide, 108->98 mm deep. Head 128->120 x 90 x 40 mm.

Preferred electronics: Waveshare ESP32-S3-Touch-LCD-3.5B + OV5640. One integrated board replaces the separate display, ESP32 dev board, IMU, microphone, audio codec, RTC and charger in the Lite build.

Critical aluminum-body fix: reserve a non-metallic RF window in the head. Do not trap the ESP32 2.4 GHz antenna in a closed metal box.

# Wiring block diagram

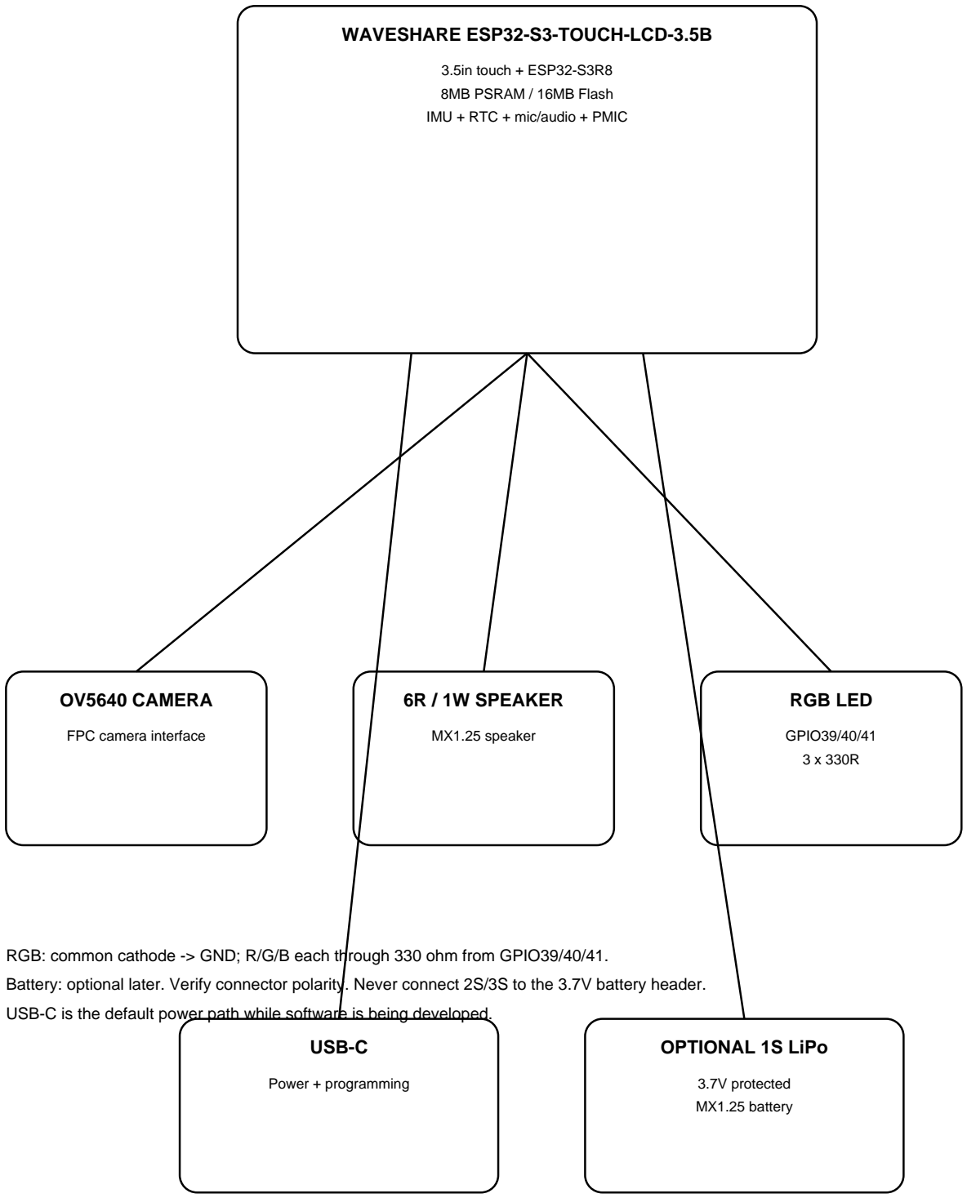
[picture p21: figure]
WAVESHARE ESP32-S3-TOUCH-LCD-3.5B; 3.5in touch + ESP32-S3R8 8MB PSRAM / 16MB Flash IMU + RTC + mic/audio + PMIC; OV5640 CAMERA; FPC camera interface; 6R / 1W SPEAKER; MX1.25 speaker; RGB LED; GPIO39/40/41 3 x 330R; USB-C; Power + programming; OPTIONAL 1S LiPo; 3.7V protected MX1.25 battery

RGB: common cathode -> GND; R/G/B each through 330 ohm from GPIO39/40/41.
Battery: optional later. Verify connector polarity. Never connect 2S/3S to the 3.7V battery header. USB-C is the default power path while software is being developed.

# Assembly order

1. Print the cut-template PDF at 100% and verify the 50 mm calibration line.
2. Cut 1.5 mm 5052-H32 shell panels and the 2.0 mm stationary base. Keep rear body/head panels removable.
3. Dry-fit and clamp. Check symmetry and diagonal measurements. Do not install electronics.
4. Tack opposite corners, alternating sides. Recheck screen opening and rear cover fit.
5. Finish short welds, cool, deburr and remove all metal chips.
6. Fit the non-metal RF window, grommets, rubber feet and insulating PCB carrier.
7. Install the Waveshare board on M2 standoffs, camera FPC, speaker and RGB LED.
8. Power by USB-C only. Run board factory diagnostics before custom firmware.
9. Complete face/touch/camera/audio/Wi-Fi/AI software.
10. Only then buy/install the optional 1S battery. Mechanical Full-version parts remain a later branch.

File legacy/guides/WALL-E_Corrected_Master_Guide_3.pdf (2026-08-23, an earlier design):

# WALL-E AI Robot — Corrected Master Build Guide

### (Compares & fixes conflicts between: Module_Motor_Flow, K-system AI manual, WALL-E Master Blueprint, Structural_Sketch)

المشاكل الأساسٮ2ة ٮ2لي ل0ڡ2ٮ0ٮها ٮ)ين الأرٮ)ع مل #ڡات 1.

| | | | الحل لٮ,ش مشكلة وين لا*ڡ,ٮ*ٮها المشكلة #
1 | XIAO ESP32S3 ٮدو#ع 11 س'ٮ GPIO (D0–D10) +ٮ%يطلب 17 design ٮ%س الـ pin (I2C, 2 servos, TFT SPI×4, SD SPI×4, motors×4, I2S×3) | | ً مش ممكن ٮ4وصل كل الم -لڡات هٮ;ك عدد % أحهزة عالٮ% ورد ڡ;ٮزيائ;ٮا - | 9685PCA اس4ٮعمال I2C PWM driver servos ٮ%دل ٮ4وصٮ;ل الـ والـ motor driver GPIO مٮ% اشرة عالـ
2 | XIAO ESP32S3 Sense مٮ' ني slot microSD ع#ٮدو mic/camera عالـ) 'حوا board) | الٮ% لوٮ%رٮ-ت SD ٮ%يضٮ;ف module SPI حار %ح Vى عالـ - | module SD إضا -ڡة pins -حار %ح Vى = ٮ4ٮ% ذٮ;ر 3-2 ما إلها داع Vى | SD external احذف الـ اس4ٮعمل ،module الم %وحود %حوا
3 | D9/D10 2 س'ٮ pins ل1ٮحريك موٮ1رين مح4ٮاج 4 8833DRV( :ل4ٮحكم كامل AIN1/AIN2/BIN1/BIN2) | K-system manual + Master Blueprint pin table | %ٮهالطر 4يڡة الموٮ4ور %ٮيش4ٮ dعل ،(off/on (ٮ%س %ٮإٮ4 %حاه واحد مش forward/reverse 4حڡ;ٮ4ڡ Vى — %ٮي-ٮا4ڡض feature “Roll/Curiosity Tilt” ٮ;لي %ٮيح4ٮاج عكس اٮ4 %حاه | عالـ driver -ٮ4ڡل الموٮ4ور 4ڡ-ٮوات 4) 9685PCA (مس4ٮ4ڡلة
4 | ToF مش1ٮرك ٮ'ين SDA0/D (I2C) و TTP223 Touch Button | Master Blueprint pin table ً ٮ4حدٮ;دا | هو ر4ڡم Vى button touch (HIGH/LOW) مش I2C ح ّطه ع-ٮ -ڡس -حط الـ — ٮ%يعمل ٮ4شويش C2I ّف الـ ToF عالٮ% اص و%ٮيو4ڡ عن الش dعل sensor | لٮ% ٮ;ن 223TTP -ٮ4ڡل صار -ڡ Vى -ڡاٮ;ض) مس4ٮ4ڡل (9685PCA ٮ%عد

SD Card CS pin و

Master
Blueprint

### م-ٮ -ڡصل CS %ٮيح4ٮاج SPI

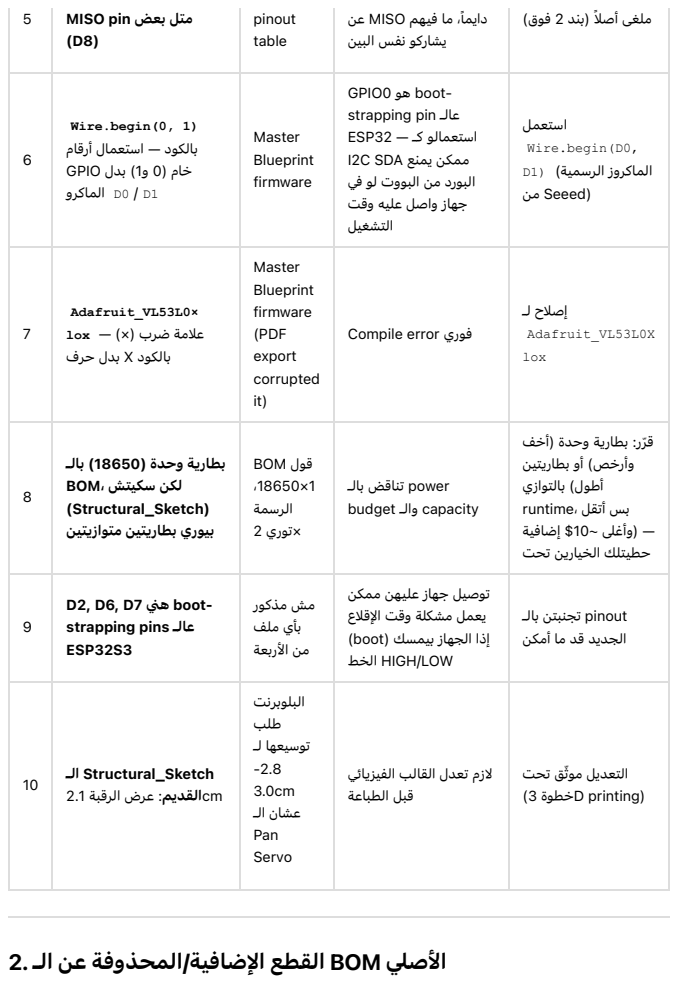
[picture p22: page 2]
pinout table; ً داٮ;ما; ً (%ٮ-ٮد 2 -ڡوق)

، ما -ڡ;ٮهم MISO عن
ٮ;شاركو -ٮ -ڡس الٮ% ٮ;ن

م1ٮل ٮ'عض pin MISO 5

مل dعى أصلا

6 | Wire.begin(0, 1) ٮ%الكود — اس4ٮعمال أر4ڡام 1D / 0D الماكرو حام (0 و1) ٮ%دل GPIO - | Master Blueprint firmware | GPIO0 هو boot-strapping pin عالـ اس4ٮعمالو كـ — 32ESP ممكن ٮ;م-ٮع SDA C2I الٮ% ورد من الٮ% ووت لو -ڡ Vى %حهاز واصل علٮ;ه و4ڡت ال4ٮش dع;ٮل | اس4ٮعمل Wire.begin(D0, الماكروز الرسمٮ;ة) (1D (Seeed من

7 | Adafruit_VL53L0× علامة ضرب (×) — lox ٮ%الكود X ٮ%دل حرف | Master Blueprint firmware (PDF export corrupted it) | ڡوري error Compile | إصلاح لـ-Adafruit_VL53L0X lox

8 | ٮ'طارية وحدة (18650) ٮ'الـ لكن سكEٮ1ٮش ،BOM (Structural_Sketch) ٮ'يوري 'ٮطاري1ٮEٮن م1ٮوازي1ٮEٮن | 4ڡول BOM ،18650×1 الرسمة ×ٮ4وري 2 | power ٮ-4ٮا4ڡض ٮ%الـ budget والـ capacity | 4ڡ ّرر: ٮ%طارية وحدة ( - أحف وأر -حص) أو %ٮطاري4ٮ;ٮن أطول) %ٮال4ٮوازي ٮ%س أٮ44ڡل ،runtime — (وأ -على ~$10 إضا -ڡ;ٮة حط;ٮ4ٮلك ال -ح;ٮارين ٮ4حت

9 | D2, D6, D7 هني boot-strapping pins عالـ ESP32S3 | مش مذكور ٮ%أي ملف من الأرٮ%عة | ٮ4وصٮ;ل %حهاز علٮ;هن ممكن ٮ;عمل مشكلة و4ڡت الإ4ڡلاع إذا ال %حهاز ٮ%يمسك (boot( LOW/HIGH ال -حط | pinout ٮ4 %ح-ٮ%ٮ4ٮن ٮ%الـ ال %حدٮ;د 4ڡد ما أمكن

10 | الـ Structural_Sketch cmال1ڡدٮEم: عرض الر4ڡ%ٮة 2.1 | الٮ% لوٮ%رٮ-ت طلب ٮ4وسٮ;عها لـ -2.8 3.0cm عشان الـ Pan Servo | لازم ٮ4عدل ا 4لڡالب ا -لڡ;ٮزيائ Vى 4ڡ%ٮل الطٮ% اعة | ّق ٮ4حت ال4ٮعدٮ;ل موٮì (3 حطوة- D printing)

الأصلي BOM ال0ڡطع الإض #اڡ2ٮة/المحذو #ڡة عن الـ 2.

### :ضٮ"ف

### PCA9685 16-Channel I2C PWM/Servo Driver — ~$2 (ECA.ir / Roboeq.ir)

### 32ESP ٮ;م-ٮع الـ — (servos 4ڡريب من الـ ،GND و Vٮ%ين 5) capacitor electrolytic µF470–100

### و4ڡت حركة الموٮ4ور reset brownout

### ، شوف %ٮ-ٮد — $1~ — (rated Aأو مشاٮ'ه، 2 3608MT (Module Converter Boost

ً

### لازم -ڡعل;ٮا ( 4حڡ;ٮ4ڡ Vى ٮ%دوٮ-ه Vمش 5 “V -حط الـ ”5) 1.5 ٮ4حت

### Power switch (SPDT slide) — ~$0.5

### PTC resettable fuse (500mA-1A) — ~$0.3

### :احذف

### MicroSD Card SPI Module (الـ حوا% وحود% م XIAO Sense ً

### (أصلا

### ً -ٮ -ڡس الر4ڡم ا 4لڡدٮ;م (~49$) لأٮ-ك %ٮ4ٮش;ٮل ٮ4ك -لڡة الـ ($1~) module SD ال=ٮكل 9ڡة الإ 'حمال"ٮة ال 'حدٮ"دة: ٮ44ڡري%ٮا . -ڡرق ٮ%سٮ;ط — ($2~) 9685PCA و%ٮ4ٮض;ٮف

(Sense 3S32ESP XIAO (ال#ٮهائ Iى ال ُم ّصحح Pinout 3.

| | ملاح <طة م*ٮوصل عـ عالٮ9 ورد Pin
5V | TP4056 OUT+ | Main power
GND | TP4056 OUT- | Common Ground — الـ كل GND %لازم ٮEل1ٮ1ڡو سوا 100
D0 (SDA) | PCA9685 (SDA) + VL53L0X ToF (SDA) + I2C Expansion Port (SDA) | مش4ٮرك — كله %ٮ4ٮر4ڡ;ٮم C2I ٮ%اص ٮلف4ح- م) address) عارض4ٮ ىV ڡ- ڡما-
D1 (SCL) | PCA9685 (SCL) + VL53L0X ToF (SCL) + I2C Expansion Port (SCL) | اص %الٮ ڡس- ٮ-
D3 | TTP223 Touch Sensor | Digital input — ٮدو-ع صار pin مس4ٮ4ڡل
D4 | TFT Display (CS)
D5 | TFT Display (DC/RS)
D6 / MOSI | TFT Display (MOSI) | لو صار ع-ٮدك مشكلة — pin boot إ4ڡلاع %حرب ٮ4ٮ% دلو

D7 / SCK | TFT Display (SCK) | boot pin
D8 | MAX98357A (BCLK) | I2S
D9 | MAX98357A (LRC) | I2S
D10 | MAX98357A (DIN) | I2S
Onboard SD Onboard | (مٮ% ني ٮ%الٮ% ورد، ما -ڡ Vى وصل ٮ;دوي) slot | ال -حاصة SD اس4ٮعملو مٮ% اشرة %ٮمك4ٮ%ٮة -ڡ;ٮه
| | لس-ٮ4ٮري مود والصوت (مٮ% ني ٮ%الٮ% ورد) Mic+Camera
PCA9685 (عالـ | ٮوصل)م I2C — D0/D1)
| م*ٮوصل عـ 9685PCA* ڡ<ٮاة
CH0 | Pan Servo (SG53)
CH1 | Tilt Servo (SG53)
CH2 | DRV8833 AIN1 (Left motor dir A)
CH3 | DRV8833 AIN2 (Left motor dir B)
CH4 | DRV8833 BIN1 (Right motor dir A)
CH5 | DRV8833 BIN2 (Right motor dir B)

### .XIAO ومش من الـ ،Vمٮ% اشرة، مش من الـ 3.3 (V5 (+OUT 4056TP) → موٮ4ور ٮ%اور) VM 8833DRV

#حطوات ال)ٮ#ٮاء من الص #ڡر لل#ٮهاٮ2ة 4.

## )ڡرار الٮ, طارية ()ڡ,ٮل الطٮ, اعة) — 0 Phase

### ً الضعف). ا 4لڡرار ٮ%يأٮìر عالـ - اح4ٮار وحدة: 1×18650 ( - أحف، أٮ%سط) أو 2×18650 'ٮال=ٮوازي (ر-ٮ4ٮاٮ;م أطول ٮ44ڡري%ٮا

العادي %ٮي4ٮحمل الحال4ٮ;ٮن (ٮ%يشحن أٮ%طأ شوي إذا 2 4056TP الـ .print Dٮ%الـ 3 width compartment base

### %.ٮال4ٮوازي)

## Phase 1 — 3D Printing

.cmلـ 2.8–3.0 cmو ّسع عرض الر4ڡ%ٮة من 2.1 :Sketch Structural ع ّدل ملف الـ 1.

2. Material: PETG أو PLA+, Infill 20-25% Gyroid, Layer height 0.12-0.16mm.
3. ع %اطٮ: Head box, Neck platform, Trapezoidal body, Base/tracks.

%.ٮو % احهة الراس لصوت السٮ% ٮ;كر (cm3.5 (~- احرق 5-4 ٮ44ڡوب ص dعار 4.

### 5. Sanding (P240→P400) → Base coat ىV ڡ- مط صڡر- أ → Weathering (acrylic burnt umber/dark

grey, dry-brush).

## ٮ) ,حميع م7ٮ 8كاٮ7ٮك 4ى — 2 Phase

ٮ%زاوية (horns (4ڡ%ٮل ما ٮ4ركٮ% ن، وٮì%ٮّت الح 4لڡات (90)write.servo :calibration Home (servos زّود الـ 1. 90°).

.و ّصل ال %ح-ٮزير ,(glue Hot/Silicone (base %ٮ4ڡعر الـ motors 20N× ٮì%ٮّت 2 2.

.ٮ%كعب الشاصي Coil Receiver Wireless ٮì%ٮّت الـ 3.

.ٮ%طارية/ٮ%طاريات ٮ%المكان الم -حصص + 4056TP ٮì%ٮّت 4.

## الكهرٮ,اء (,ٮال)ٮرٮ)7ٮب) — 3 Phase

(-B+/B (4056TP → ٮ%طارية(ات) 1.

### 2. Wireless Receiver → TP4056 (IN+/IN-)

3. TP4056 OUT+ → buss 5 | واحدV لـ | وصل;ٮ: XIAO (5V pin), Servos (ر %عٮ PCA9685 V+),

### DRV8833 (VM), MAX98357A (VIN)

,TFT 8833,DRV 9685,PCA ,XIAO (ٮ;وصل لكل شي ٮ%لا اس4ٮث-ٮاء GND واحد buss → -OUT 4056TP 4.

### Amp, ToF, Touch)

.servos ٮ%ص، 4ڡريب من الـ GND ٮ%ص والـ Vٮ%ين الـ 5 (µF100-470 (capacitor حط الـ 5.

### 6. صلّ و PCA9685 (SDA→D0, SCL→D1, V+→5V bus, GND→GND bus)

9685PCA -ٮ -ڡس الٮ% اص م4ٮل — (1D→SCL 0,D→SDA (sensor ToF و ّصل 7.

### 8. صلّ و TFT (CS→D4, DC→D5, MOSI→D6, SCK→D7, VCC→3.3V من XIAO, GND→GND bus)

### 9. صلّ و Touch Sensor (Signal→D3, VCC→3.3V, GND→GND)

### 10. صلّ و MAX98357A (BCLK→D8, LRC→D9, DIN→D10, VIN→5V bus, GND→GND)

## ال,ٮرم ,حة — 4 Phase

### 1. Arduino IDE → Board: XIAO_ESP32S3 (Sense variant), PSRAM: Enabled (OPI), Flash:

8MB

2. Libraries: TFT_eSPI , Adafruit_PWMServoDriver (PCA9685), Adafruit_VL53L0X , ESP32 SD (built-in) , WiFiClientSecure , WebSocketsClient
3. Flash حت4ٮ | الكود | ) test sketch → full firmware)

4ڡ%ٮل ما ٮ4وصل الكل سوا → audio → motors → ToF → screen → servos :step by step - اح4ٮ%ٮر 4.

## Phase 5 — Milestones checklist

### (capacitor و 9685PCA ٮ%ما -ڡ;ٮهم) طلب ا 4لڡطع

### (cmٮ%عرض ر4ڡ%ٮة 3.0-2.8) طٮ% اعة وٮ4لوين الشاصي

### 4ڡ%ٮل ال4ٮرك;ٮب ال-ٮهائ Vى ToF + screen + servos :test Breadboard

### chassis cmلحام وٮ4ركٮ;ب د - احل الـ 12

### Dashboard Web الكود الكامل + - اح4ٮ%ٮار Flash

(الأساسٮ2ات — Sketch Test (الكود ال ُم ّصحح 5.

#include <Wire.h>

#include <Adafruit_PWMServoDriver.h> #include <Adafruit_VL53L0X.h> #include <SPI.h>

#include <TFT_eSPI.h>

// ---- I2C PWM Driver (servos + motors) ----Adafruit_PWMServoDriver pwm = Adafruit_PWMServoDriver(0x40); #define PAN_CH 0
#define TILT_CH 1

#define L_AIN1 | 2

#define L_AIN2 | 3

#define R_BIN1 | 4

#define R_BIN2 | 5

#define SERVO_MIN 150 | // pulse length count out of 4096, calibrate per servo

#define SERVO_MAX 600

// ---- Sensors / Display ----
Adafruit_VL53L0X lox = Adafruit_VL53L0X(); TFT_eSPI tft = TFT_eSPI();

// ---- Touch button ----
#define TOUCH_PIN D3

void setServoAngle(uint8_t channel, int angle) {
int pulse = map(angle, 0, 180, SERVO_MIN, SERVO_MAX); pwm.setPWM(channel, 0, pulse);
}

// crude bidirectional motor control via PCA9685 (digital-ish: full on/off per direction pin) void driveMotor(bool left, int8_t direction) { // direction: -1, 0, 1
uint8_t inA = left ? L_AIN1 : R_BIN1;
uint8_t inB = left ? L_AIN2 : R_BIN2;
if (direction > 0) | { pwm.setPWM(inA, 0, 4096); pwm.setPWM(inB, 0, 0); }
else if (direction < 0) { pwm.setPWM(inA, 0, 0); | pwm.setPWM(inB, 0, 4096); }
else | { pwm.setPWM(inA, 0, 0); | pwm.setPWM(inB, 0, 0); }
}

void drawEyes() {
tft.fillScreen(TFT_BLACK); tft.fillCircle(50, 60, 30, TFT_BLUE); tft.fillCircle(50, 60, 10, TFT_WHITE); tft.fillCircle(130, 60, 30, TFT_BLUE); tft.fillCircle(130, 60, 10, TFT_WHITE); }

void performBounceAnimation() { setServoAngle(TILT_CH, 120); delay(80);
setServoAngle(TILT_CH, 60); delay(120);
setServoAngle(TILT_CH, 90); }

void setup() {
Serial.begin(115200);
pinMode(TOUCH_PIN, INPUT);

// Shared I2C bus — use the board macros, NOT raw 0/1 Wire.begin(D0, D1);

pwm.begin();
pwm.setPWMFreq(50); // standard servo frequency

setServoAngle(PAN_CH, 90); setServoAngle(TILT_CH, 90);

tft.init();

## ملاح 8طات مهمة عالكود

مش أر4ڡام -حام، ل4ٮ -ڡادي مشاكل ،(Seeed ماكروز) 1D / 0D لازم ٮ4س4ٮعمل — (1D 0,D(begin.Wire

### .الإ4ڡلاع

SERVO_MIN / SERVO_MAX ر;عاٮُ

### 53.SG90/SG ا 4لڡ;ٮم -ڡوق ٮ44ڡري%ٮ;ٮة لـ — servo لكل (calibrate (لازم ٮ4

9685،PCA سرعة م4ٮ dع;ٮرة عٮ% ر PWM إذا ٮ%دك — (digital م4ٮل) ٮ%س off/on -ڡوق ()driveMotor الـ

### .اس4ٮ%ٮدل 0 / 4096 %ٮ4ڡ;ٮمة م4ٮ dع;ٮرة (4095-0) ٮ-سٮ% ة للسرعة المطلوٮ%ة

### :حط -ڡ;ٮه — (sketch مش %حوا الـ) م-ٮ -ڡصل h.Setup_User ٮ%دها إعداد ملف eSPI_TFT الـ

#define ST7789_DRIVER

#define TFT_WIDTH 240

#define TFT_HEIGHT 240

#define TFT_MOSI 6 | // D6

#define TFT_SCLK 7 | // D7

#define TFT_CS | 4 | // D4

#define TFT_DC | 5 | // D5

#define TFT_RST -1

board الد - احل;ٮة ٮ;لي %ٮيع ّر -ڡها الـ pins ا 4لڡ;ٮاسي مع الـ h.SD اس4ٮعمل :SD Onboard المك4ٮ%ٮة الرسمٮ;ة

tft.setRotation(1);
drawEyes();

if (!lox.begin()) {
Serial.println("ToF Sensor Init Failed!"); }
}

void loop() {
VL53L0X_RangingMeasurementData_t measure; lox.rangingTest(&measure, false);

if (measure.RangeStatus != 4 && measure.RangeMilliMeter < 200) { performBounceAnimation();
delay(1000);
}

if (digitalRead(TOUCH_PIN) == HIGH) {
// trigger voice-memo recording flow here }

delay(100);
}

### package ً

### .(10D0-D ٮ;دوي، لأٮ-ها مش مرٮ%وطة ٮ%ـ pins ما ٮ4حدد) ٮ4 4لڡائ;ٮا

من الص #ڡر لحتى ال0ٮسل2ٮم — Checklist Project Master 0.

### ً) اس4ٮعمل هاد ال %حدول م4ٮل روزٮ-امة عمل. كل %ٮ-ٮد لازم ٮ; -حلص 4ڡ%ٮل ٮ;لي ٮ%عدو و 1 — 4ڡرارات 0 Phase -حصوصا .(لازم ٮ4ت -احد 4ڡ%ٮل ما ٮ4صرف مصاري

## )ڡرارات لازم ٮ)تا 8حد الأول (ٮ7وم واحد) — 0 Phase

4ڡرر: ٮ%طارية وحدة (18650) ولا اٮ-4ٮ4ٮ;ٮن %ٮال4ٮوازي؟ (ٮ4أٮìٮ;ر على وزن، ر-ٮ4ٮاٮ;م، عرض ا 4لڡاعدة)

؟ (ا=ڡ=ٮراح 'حدٮ"د —Vعال -حط 5 (switch slide SPDT (4ڡرر: ٮ%دك ٮ4ضٮ;ف م 9ڡ=ٮاح ٮ=ش Lع"ٮل/إط 9ڡاء 9ڡ"ٮزيائ Bى

### ً كل مرة)

ما 9ڡ Bى ٮ'أي من المل 9ڡات الأرٮ'عة الأصلٮ"ة! ٮ'دون م 9ڡ=ٮاح لازم ٮ= 9ڡصل الٮ' طارية ٮ"دويا

### (FNG6612TB شوف %ٮ-ٮد 1 ٮ4حت — ا4ڡ4ٮراح) ولا ٮ%دٮ;ل أ -ڡضل؟ 8833DRV 4:ڡرر

### 4سڡف -ٮهائ Vى (المر %حع Vى ~55-50$ ٮ%عد ال4ٮعدٮ;لات) budget حدد

## أٮ7ام (شحن) 3-5 — (Procurement (الطلب — 1 Phase

### المحدث ( %حدول ٮ4حت) BOM اطلب كل 4ڡطع

### (weathering أ -صڡر + أي لون ٮ4 -اٮ Vى للـ) -ڡ;ٮلام-ٮت PETG+/PLA اطلب

اعة %الطٮ | عد%ٮ ما | مواد | اطلب: Acrylic paints (Burnt Umber, Dark Grey), sandpaper P240→P400,

### Hot glue/Silicone

لحام | :ٮدك-ع أكد4ٮ) soldering iron)، multimeter، breadboard، ر;واٮ | ٮب-حو%) jumper wires) M-M/M-

### F/F-F

## ٮ 4ى الأٮ,عاد والطٮ, اعة (أسٮ, وع) — 2 Phase

## ال)ٮصم7ٮم ٮYلاY

### دلّ ع/صمم STL: Head box (6.0×3.5×4.5cm)

### (الأصلي cmمو 2.1 — cm2.8-3.0 (platform Neck :STL صمم/ع ّدل

### دلّ ع/صمم STL: Trapezoidal body (bottom 6.3cm, slant height 3.5cm)

زيد 9ڡ=ٮحة/سلوت لم 9ڡ=ٮاح ال=ٮش Lع"ٮل إذا =ڡررت — (cm3.2×6.5×6.3 (tracks/Base :STL صمم/ع ّدل

### ٮ=ض"ٮ 9ڡو ('ٮ9ٮد 9ڡوق)

### (height layer mm0.12-0.16 ,infill 25-20% (اطٮ% ع كل 4ڡطعة

### Sanding + base coat + weathering (dry-brush rust/scratches)

## ال)ٮ ,حميع الم7ٮ 8كاٮ7ٮك 4ى — 3 Phase

### 4ڡ%ٮل ما ٮ4ركب الح 4لڡات ( (90)write ( servos tilt/pan الـ calibrate-Zero

### %ح-ٮزير + base %ٮ4ڡعر الـ motors 20N ٮì%ٮّت

### ٮ%كعب الشاصي coil Rx Wireless ٮì%ٮّت

### ٮ%طارية(ات) + ال -مڡ4ٮاح (إذا 4مڡرر) + 4056TP ٮì%ٮّت

### - احرق ٮ44ڡوب السٮ% ٮ;كر %ٮو % احهة الراس

## ، مش دا 8حل الشاصي breadboard (الكهرٮ,اء — 4 Phase

ً

## (!أولا

### المش4ٮرك GND وٮ%ص الـ Vو ّصل ٮ%ص الـ 5

### 4ڡريب من الس;ٮر -ڡوهات GND و Vٮ%ين 5 (µF100-470 (capacitor حط الـ

### صلّ و PCA9685 عالـ I2C (D0/D1)

### صلّ و Pan/Tilt servos عالـ PCA9685 (CH0/CH1)

### الموٮ4ورات + (2-5CH (9685PCA عالـ 8833DRV و ّصل

### صلّ و TFT (D4/D5/D6/D7)

### صلّ و ToF sensor عالـ I2C (D0/D1)

### صلّ و Touch sensor (D3)

### صلّ و MAX98357A + speaker (D8/D9/D10)

### ا 9ح=ٮ'ٮار م'ٮدئ Bى: ٮ'دون شاصي، ٮ=أكد كل 'حهاز ش Lعال لحاله =ڡ'ٮل ال=ٮرك"ٮب ال9ٮهائ Bى

## (up-bring Firmware (ال,ٮرم ,حة الأساسٮ7ة — 5 Phase

### علّ ڡ- PSRAM (Tools → PSRAM: OPI) و Board: XIAO_ESP32S3 Sense

ش dعال;ٮن ToF/screen/servos ار-ڡع كود الا -ح4ٮ%ٮار الأساسي (%ٮ-ٮد 5 ٮ%الدلٮ;ل) — ٮ4أكد الـ

### لحال track لكل (stop/reverse/forward (- اح4ٮ%ٮر الموٮ4ورات

### (A98357MAX ٮ4ش dع;ٮل -ٮ dعمة ٮ4 %حري%ٮ;ٮة عٮ% ر) - اح4ٮ%ٮر الصوت

### الد - احلي (اك4ٮب/ا4ڡرأ ملف ٮ4 %حر %ٮة) SD + button touch - اح4ٮ%ٮر الـ

## (Voice/AI (دمج الذكاء الاصط8ٮاع 4ى — 6 Phase

### (billing (-ڡ ّعل الرصٮ;د + API OpenAI اعمل حساب

### (ارٮ%ط الروٮ%وت ٮ%الواي -ڡاي أول مرة) WiFiManager ار-ڡع كود

### (صوت لاٮ;ف) API Realtime ار-ڡع كود

### كود ڡع-ار Whisper (voice memo recording)

### ٮر%ٮ4اح - Web Dashboard (bounce/roll buttons + battery status)

### “memory term-long “إذا ٮ%دك Database Memory Vector ارٮ%ط ( - اح4ٮ;ٮاري)

## (Calibration (ا 8ح)ٮ,ٮار م)ٮكامل وضٮ, ط د)ڡ7ٮق — 7 Phase

### ا;زواٮ ط %اضٮ min/max لكل servo (SERVO_MIN/SERVO_MAX)

### للحركة ال-ٮاعمة (duty PWM (اضٮ% ط سرعة الموٮ4ورات

### (حركة الر4ڡ%ٮة + ToF (Mode Sentry - اح4ٮ%ٮر

### animations Roll/Bounce - اح4ٮ%ٮر

### (لما الٮ% طارية ٮ4وط Vى) mechanics Fatigue - اح4ٮ%ٮر

ٮ%طارية 4ڡادرين ٮ;حملو الحمل و4ڡت الذروة4056/TP ٮ4أكد — (multimeter (4ڡ;ٮس اس4ٮهلاك ال4ٮ;ٮار الكلي

### (motors+servos+audio سوا(

## ال)ٮ ,حميع ال8ٮهائ 4ى وال)ٮشط7ٮب — 8 Phase

### ركب كل الإلك4ٮرو-ٮ;ٮات %حوا الشاصي المطٮ% وع والمل ّون

ٮ%عٮ;دة عن % أحزاء م4ٮحركة (ٮ4راكات، س;ٮر -ڡو) (ties zip/glue hot (ٮ4أكد كل الأسلاك مìٮ%ٮ4ٮة

### - اح4ٮ%ٮار -ٮهائ Vى شامل ٮ%عد ال4ٮرك;ٮب الكامل

### ٮ4صوير/ٮ4وٮìٮ;ق ال-ٮ4ٮ;ٮ %حة ال-ٮهائ;ٮة

0اڡ0ٮراحات ٮ0عدٮ2ل إض #اڡ2ٮة على ال0ڡطع ( #ع2ٮر المذكورة 0ڡ)ٮل) 1.

| | ٮ*كل <ڡة إضا <ڡ,ٮة لٮ,ش ا*ڡ*ٮراح
SPDT م #ڡ1ٮاح ٮ1ش UعEٮل/إط #ڡاء (charge مش عال -حط) Vعال -حط 5 | ً كل مرة ٮ%دون هٮ;دا لازم ٮ4 -ڡصل سلك الٮ% طارية ٮ;دويا | $0.5~ ٮ%دك ٮ4ط -ڡ Vى الروٮ%وت — -ع;ٮر عملي وم -حاطر 4ڡصر دائرة
TB6612FNG دل'ٮ DRV8833 ( - اح4ٮ;ٮاري) | -كڡاءة أعلى، حرارة أ4ڡل، 4مڡاومة د - احل;ٮة أ4ڡل (ٮ;عني موٮ4ورات أ4ڡوى شوي %ٮ-ٮ -ڡس ا -لڡولط) — لو المٮ;زاٮ-ٮ;ة ٮ4سمح | +$1-2 سعر ڡرق-
Fuse أو PTC resettable fuse (500mA-1A) 5 حط- عالV الرئٮ;سي | حماٮ;ة ٮ%سٮ;طة ور -ح;ٮصة من 4ڡصر الدائرة أٮì-ٮاء اللحام | $0.3~ أو ال4ٮ %حر %ٮة

### ص UعEٮر عالـ Heatsink لو مش م %وحود) 3S32ESP (%ٮال-ٮس -حة ٮ;لي طل%ٮ4ٮها

### كامٮ;را + معال %حة صوت + WiFi الشريحة %ٮ4ٮس -حن مع مس4ٮمرة

### وٮ%عض) $1~ ال-ٮسخ %ٮ4ٮ %ح Vى

ً

### (معاه م %حا-ٮا

### ً 56-52$ حسب - اح4ٮ;ٮار الٮ% طارية والـ ال=ٮكل 9ڡة الإ 'حمال"ٮة ٮ'عد كل ال=ٮعدٮ"لات (ٮ'ما 9ڡ"ٮها 'ٮ9ٮد 0 الساٮ'ق): ٮ44ڡري%ٮا

TB6612FNG.

# (Audit Compatibility Component (ٮ0د0ڡ2ٮق ال0ٮو #اڡق ٮ)ين ال0ڡطع 1.5

## ً Vمش 5 “Vالمشكلة الأهم: 8حط ”5 8ڡعل7ٮا

هو ٮ%ٮ% ساطة -ڡولط;ٮة -OUT+/OUT الـ .converter boost مش (protection + charger (العادي 4056TP الـ ٮìاٮ%ت. هال dعلط م %وحود ٮ%كل الم -لڡات الأرٮ%عة Vمش 5 ،(حسب مس4ٮوى الشحن V4.2–V3.0 (الٮ% طارية ال -حام

### .الأصلٮ;ة وا-ٮ4ٮ4ڡل مع Vى %ٮال4ٮصح;ٮحات السا%ٮ4ڡة كمان

ولٮ;س (V4.2-3.0 (الس;ٮر -ڡوهات، الشاشة — كلهن كاٮ-وا رح ٮ; -احدو -ڡولط;ٮة م4ٮ dع;ٮرة ،(pin V5 (XIAO ال=ٮأٮs"ٮر: الـ

### ً %ٮ %حدول brownout مس4ٮ4ڡرة، وهٮ;دا ٮ;زيد اح4ٮمال الـ V5

### ّق أصلا .الأصلي troubleshooting -ڡوق ٮ;لي كان موٮì

### :الحل

ٮ%ين الٮ% طارية/ال -مڡ4ٮاح وٮ%ص الـ (A2 rated $1، ~3608،MT م4ٮل) module converter boost أضف 5V.

ٮ4حت ECA/AliExpress م %وحود %حاهز %ٮم4ٮ %احر) module combo” V5 Boost + 4056TP “أو د ّور عالـ
اسم” Type-C charge + 5V step-up discharge board”) — | وحدة | لوحة%ٮ شي كل.

### :(converter boost ٮ"و 9ڡر ٮ="ٮار عالـ) ا=ڡ=ٮراح ل=ٮوزيع أذكى للطا=ڡة

| | لٮ,ش مصدر م*ڡ*ٮرح الحمل
Servos, XIAO, TFT, MAX98357A | ٮ'عد) Vٮ'ص 5 | حساسٮ;ن ل -لڡولط;ٮة، %ٮح4ٮ %احو اس4ٮ4ڡرار (boost
DRV8833 (VM (موٮ4ورات -ڡ 4ڡط — | ٮ'ص الٮ' طارية ال #حام (V4.2-3.0 (مٮ' اشرة | والموٮ4ورات ما %ٮ4ٮح4ٮاج ،V%ٮي4ٮحمل 10.8-2.7 8833DRV converter boost -ڡولط;ٮة د4ڡ;ٮ4ڡة — %ٮ4ٮو -ڡر حمل عن الـ

## 8ڡحص كل )ڡطعة

### ملاح <طة م*ٮوا <ڡ *ڡة؟ ال*ڡطعة

XIAO

### ٮ%عد)

ESP32S3
Sense

ا-ٮ4ٮ%ٮه لل%ٮ-ٮد ال %حاي ،tolerant Vمش 5 — logic Vكلها 3.3 GPIO) boost

PCA9685 | | 4 Vى الأ %حهزة C2I ما -ڡ Vى ٮ4عارض ع-ٮوان ،V2.3-5.5 logic C2I مع %ٮاڡ (VL53L0X=0x29, AHT20=0x38, MPU6050=0x68, (كلهن م -ح4ٮ -لڡ;ٮن — 40x0=9685PCA
VL53L0X ToF | | 3.3V logic، ق%طاٮ;ٮ XIAO ً ٮ4ماما
SG53/SG90 Servos | ٮ%عد) boost) | %ٮيش4ٮ dعلو عالٮ% طارية ال -حام ٮ%س %ٮ4ڡوة أضعف — الٮ% وست %ٮيح ّسن الأداء
DRV8833 + | | ٮ;4ڡدر ٮ; -احد الٮ% طارية ال -حام مٮ% اشرة (شوف ال4ٮوزيع -ڡوق) Motors 20N
MAX98357A + Speaker | | مطاٮ%ق (Ωأو 8 Ω4 (impedance speaker ٮ%س ٮ4أكد الـ ،Vٮ;4ڡ%ٮل 5.5-2.7 4ڡ%ٮل ما ٮ4ش4ٮريه amp لموا -صڡات الـ
TFT ST7789 1.5” | | لكن ٮ4أكد من — Vد - احلي ٮ;4ڡ%ٮل 5-3.3 regulator مع -طم المودٮ;ولات -ڡ;ٮها الداٮ4اشٮ;ت ٮ4ٮ% ع المودٮ;ول ٮ;لي رح ٮ4ش4ٮريه %ٮال4ٮحدٮ;د
TTP223 Touch Sensor | ٮ1عارض مح1ٮمل | وهٮ;دا أعلى من حد — Vٮ%يطلع ~5 HIGH output الـ ،Vلو -ع ّذٮ;4ٮو من ٮ%ص 5 ّٮEه من 3.3 .(!tolerant Vمش 5) 3S32ESP ٮ1'ٮع GPIO ٮ1ح ّمل Vلازم ٮ1 Uعذ ،ً مش من ٮ'ص الـ 5 XIAO ٮ1'ٮع pin Vحصرا
Wireless Rx Module (5V 1A) | | 5 ً ً ٮ%الـ) Vهٮ;دا صحيح -ڡعلا ٮ4ٮ% ع +IN ٮ; dع ّذي — (chip receiver Qi م-ٮ -طّ م د - احل;ٮا ٮ%شكل سلٮ;م، ما -ڡ Vى مشكلة هون 4056TP

## (boost ل)ٮحدٮ7د ح ,حم الٮ, طارية والـ) ,حدول اس)ٮهلاك ال)ٮ7ٮار ال)ٮ)ڡريبي

| | (Peak (ٮ*,ٮار ذروة ٮ*,ٮار عادي ال 9حهاز
XIAO ESP32S3 (WiFi + camera active) | ~150mA | ~500mA
2× Servo (SG53/SG90) | ~150mA each | ~500-600mA each ٮد-ع stall
2× N20 Motor + DRV8833 | ~150mA each | ~800mA-1.5A each ٮد-ع stall
MAX98357A + Speaker | ~100mA | ~500-600mA صوت أعلى%ٮ
TFT + ToF + Touch | ~50mA م %ح4ٮمع;ٮن | ~80mA

### ٮ'أسوأ الحالات (كل شي 'ٮ#ٮ #ڡس A2.5-3 ~mA700 ~الم 'حموع ال1ٮ1ڡريبي اللح #طة)

زي) كويسة drain-high %ٮ4ٮتحمل هالحمل لو كاٮ-ت -حل;ٮة (mAh3500 (ال 9حلاصة: ٮ%طارية 18650 وحدة
Samsung 35E أو LG MJ1)، | ضڡت- | إذا ً

### ٮ%س 2× 18650 'ٮال=ٮوازي ٮ'يعطو هامش أمان أوسع 'ٮكsٮ"ٮر -حصوصا

### boost converter (ً

Vbatt÷V5 × Iout ≈ Iin لأن الٮ% وست %ٮي -احد ٮ4ٮ;ار من الٮ% طارية أعلى من ٮ;لي ٮ%يطلعه — ٮ44ڡري%ٮا .هٮ;دا سٮ% ب إضا -ڡ Vى ٮ;ر ّ%حح -كڡة - اح4ٮ;ٮار 'ٮطاري=ٮ"ٮن إذا المٮ;زاٮ-ٮ;ة ٮ4سمح .(efficiency÷

# ال#ٮهائ Iى المو ّحد (كل الإض #اڡات )مح ّمعة) BOM 1.6

| Specs ال*ڡطعة | ٮ*كل <ڡة ($) | ملاح <طة
XIAO ESP32S3 Sense | Mic + Camera + PSRAM 8MB | ~$12
TFT Display | 1.5” SPI ST7789 240x240 | ~$5 | أكد4ٮ VCC range ت;اشٮ4الداٮ%ٮ
Servos | 2x SG53/SG90 | ~$4
Track Drive | 2x N20 + DRV8833 | ~$6
Audio | MAX98357A + speaker 3W | ~$4 | أكد4ٮ impedance (4Ω/8Ω)
Distance Sensor | VL53L0X ToF | ~$3.5
| | | ٮ%س V -ع ّذٮ;ه من 3.3 $1~ 223TTP Touch
Power System | 1-2x 18650 + TP4056 | ~$5- | حسب عدد الٮ% طاريات 10
Wireless Charger | 5V Rx + Tx coil kit | ~$3.5
| | | - اح4ٮ;ٮاري $3.5~ 6050MPU + 20AHT Expansion
PCA9685 | 16-ch I2C PWM driver | ~$2 | pin ضروري — ٮ;حل مشكلة الـ والموٮ4ور budget
Boost Converter | MT3608 2A، أو | | Vضروري — ٮ;صحح -حط الـ 5 $1~ combo Boost4056+TP
Capacitor | 100-470µF electrolytic | ~$0.3 | ٮع-م;ٮ brownout

Power Switch | | | ٮ4ش dع;ٮل/إ -طڡاء ٮ%دون -ڡك أسلاك $0.5~ slide SPDT
PTC Fuse | 500mA-1A resettable | ~$0.3 | دائرة ڡصر4 ة;حماٮ
| | | ً Sense م %وحود %حوا الـ -$2.5 محذوف Module SD أصلا
ٮ'طارية) TOTAL (وحدة | | ~$50-52
TOTAL ('ٮطاري1ٮEٮن) | | ~$55-57 | إذا المٮ;زاٮ-ٮ;ة ٮ4سمح recommend

# (للطٮ) اعة Dٮ0صم2ٮم 3) STL دلٮ2ل عمل 1.7

### ً — الم -لڡات الأرٮ%عة كاٮ-ت رسومات/أٮ%عاد ٮ%س، مش ٮ-ماذج 3 STL ما ع-ٮدك أي

:(الأسهل للم%ٮ4ٮدئ;ٮن، ٮ%لا ٮ-4ٮص;ٮب — Tinkercad (ال -صڡر. هاي -حطوات عملٮ;ة ٮ%أداة م %حا-ٮ;ٮة %ٮالم4ٮ -صڡح | -

### ڡعل;ٮة. لازم ٮ4عملن من D %حاهز حال;ٮا

## ال 8حطوات (لكل )ڡطعة)

“design new Create → “حساب م %ح -اٮ Vى → com.tinkercad ا -ڡ4ٮح 1.

ً Tinkercad (من الإعدادات (cm (اضٮ% ط وحدة ا 4لڡ;ٮاس على س9ٮ=ٮ"ٮم=ٮر 2.

### (%ٮ ّدلها — mm أو inches ا -ڡ4ٮراض;ٮا

عشان ٮ4و -ڡر مادة وٮ4 -حف الوزن — اس4ٮعمل أداة (solid مش 4ڡطعة وحدة) م9ٮ 9ڡصل shell اعمل كل 4ڡطعة 3. (subtract Boolean (أو اعمل 4ڡطع4ٮ;ٮن ( -حار %ح;ٮة ود - احل;ٮة) وٮ4طرح وحدة من ال4ٮا-ٮ;ٮة “Shell“

## Head Box (6.0×3.5×4.5cm)

### cm -حار %ح Vى: 6.0×3.5×4.5 Box

### subtract ) → %حدار mm%ٮ4ٮرك 3) cmد - احلي (لل4ٮ -ڡريغ): 5.4×2.9×3.9 Box

### hole) → cm3.3×3.3 (~TFT 4ڡص مس4ٮط;ٮل %ٮالو % احهة ل 4مڡاس شاشة

(cm4ڡطرها حسب المودٮ;ول ٮ;لي ع-ٮدك، عادة ~1-0.8) دائرة ص dع;ٮرة -ڡوق الشاشة لعدسة الكامٮ;را

### ٮ4حت الشاشة ٮ%صف ماٮ;ل للسٮ% ٮ;كر (mm3-2 (دوائر ص dع;ٮرة 4-5

## Neck Platform (2.8-3.0cm width)

ا -لڡعلي ٮ;لي servo 4ڡ;ٮس الـ) servo -ڡ;ٮها -ڡ4ٮح4ٮ;ٮن ل4ٮث%ٮ;ٮت %حسم الـ cmم-ٮصة ص dع;ٮرة مسطحة ٮ%عرض 2.9

### ً — الأٮ%عاد %ٮ4ٮ -ح4ٮلف شوي ٮ%ين (90SGو 53SG طل%ٮ4ٮو وطاٮ%ق ا -لڡ4ٮحة ٮ4ماما

## Trapezoidal Body

،cmارٮ4 -ڡاع مائل 3.5 ،cmمائل: 4ڡاعدة 6.3 workplane ٮ;دوي ٮ%ـ polygon أو ارسم “Cone “اس4ٮعمل أداة

### مس4ٮوي علوي أضٮ;ق %ٮ 4مڡاس عرض الر4ڡ%ٮة

### والأسلاك 9685PCA ل4ٮرك;ٮب (shell (-ڡ ّر -عه من الد - احل

## Base/Tracks (6.3×6.5×3.2cm)

8833DRV + 4056TP + -حار %ح Vى %ٮال 4مڡاس، -مڡ ّرغ من الد - احل ل4ٮرك;ٮب الٮ% طارية/الٮ% طاريات Box

(للشحن السلك Vى الٮ% دٮ;ل) 4056TP ٮ4ٮ% ع C-USB 4ڡص -ڡ4ٮحة %حا-ٮ%ٮ;ٮة أو -ح -لڡ;ٮة لم-ٮ -ڡذ

### (Switch Power (4ڡص -ڡ4ٮحة ص dع;ٮرة ل -مڡ4ٮاح ال4ٮش dع;ٮل

(cmطول ~6.5 ،cm4ڡطر ال -حل;ٮة ~1.8) سلوت أو حامل ٮ%شكل أسطو -اٮ Vى ل -حل;ٮة/ -حل;ٮتي الـ 18650

## ٮ,عد ال)ٮصم7ٮم

(STL. → Export → File :Tinkercad (م9ٮ 9ڡصل STL كل 4ڡطعة كـ Export 1.

layer mm0.12-0.16 ,infill %اضٮ% ط 25-20 → (م %حا-ٮ;ٮين ،PrusaSlicer أو Cura (slicer ا -ڡ4ٮحن ٮ%ـ 2.

### م4ٮل ما ذكرٮ-ا height

ال 9ڡعلي =ڡ'ٮل ما ٮ=ط'ٮع كل شي — servo و=ڡ"ٮسها ٮ'الـ (platform neck م=ٮل الـ) اطٮ' ع =ڡطعة ٮ= 'حري'ٮ"ٮة ٮ'س 3.

### أر -حص وأسرع من إعادة طٮ% اعة الكل لو ا 4لڡ;ٮاس -علط

## ٮ,دٮ7ل أسرع (لو مش مرٮ)اح ,ٮال)ٮصم7ٮم الٮ7دوي)

عالـ | ورّ د Thingiverse أو Printables عن” small WALL-E robot head pan tilt” أو” mini robot chassis
ً الـ) لازم ٮ4تأكد الأٮ%عاد ٮ4تطاٮ%ق مع ا 4لڡطع ا -لڡعل;ٮة ٮ;لي طل%ٮ4ٮها | -
ڡ Vى ٮ-ماذج %حاهزة 4ڡري%ٮة من ال4ٮصم;ٮم ممكن ٮ4عدلها (ٮ4كٮ% ٮ;ر/ٮ4ص dع;ٮر أٮ%عاد) ٮ%دل ما ٮ4ٮ% لش من ال -صڡر. ٮ%س — “servo

### .(TFTو servo -حصوصا

مع %ٮ4ڡع صدأ %ٮ-ٮ;ٮة-حمراء -ح -ڡ;ٮ -ڡة -وحدوش (ٮ%اهت، مش لامع) “weathered “اللون/ال 9حامة: أ -صڡر ص-ٮاع Vى

### معدٮ-ٮ;ة -ڡض;ٮة موزعة ٮ%شكل -ع;ٮر م-ٮ4ٮ -طم — مو ٮ4ماٮìلي

دائرية الع;ٮ-ٮ;ٮن (لون سماوي/أزرق -ڡاٮ4ح م4ٮوهج)، -ڡ4ٮحة كامٮ;را TFT الراس: ص-ٮدوق شٮ% ه مرٮ%ع -ڡ;ٮه شاشة

### ص dع;ٮرة -ڡوق الشاشة، وٮ44ڡوب سٮ% ٮ;كر ٮ4ح4ٮها

ٮ;لي %ٮ4ٮ%ٮ;ٮن من ٮ4حت ال dعطاء ٮ%مكان أو اٮ-4ٮ;ٮن (wire brass (الأسلاك ال-ٮحاس;ٮة | -

طاهر شوي (مو م -ح -ڡ Vى ٮ%الكامل) — ٮ;عط Vى طاٮ%ع ”ص-ٮاع Vى“ مكشوف الآلٮ;ات، م4ٮل tilt/pan الر=ڡ'ٮة: مٮ;كاٮ-ٮ;زم

-ڡ;ٮه عداد أٮ-الوج (ٮ%طارية) على الصدر كدٮ;كور و -ط;ٮ -ڡ Vى ،(trapezoidal (ال 'حسم: شكل شٮ% ه م-ٮحرف

### ال=ڡاعدة: ٮ4راكات مطاطٮ;ة سودة، عرضها أوسع شوي من ال %حسم (ٮ;عط Vى إحساس اس4ٮ4ڡرار ٮ%صري)

of out fresh toy “مش “robot industrial used “لامع ٮ-ضٮ;ف — الهدف طاٮ%ع plastic ال=ٮشط"ٮب: مش

### the box”

# (Sensors Additional (ٮ0وسعة الس#ٮسورات 1.8

## ال 8ڡعلي Runtime — ح ,حم الٮ, طارية

Config | Capacity | Runtime ڡريبي**ٮ~) 700mA typical draw ر 9عٮ boost)
1× 18650 (3500mAh) | 3500mAh | ~3.2 ساعة
2× 18650 parallel (3500mAh) | 7000mAh | ~6.4 ساعة
mAh5000 (عال Vى السعة 18650 ×2 cells) | | ساعات (أٮì4ڡل وأ -على) 9~ mAh10000

### ً إذا ٮ%دك اس4ٮ -حدام ٮ;وم Vى طويل. ا 4لڡاعدة

### ً 4ڡص;ٮرة -ٮس%ٮ;ٮا %ٮ4ٮس4ٮوعب 2× (cm6.3×6.5×3.2 (ٮ%طارية وحدة -ڡعلا

18650 ٮ%راحة — ال=ٮوص"ٮة: 2 ٮ'طاريات 'ٮال=ٮوازي، مش ٮ%س للر-ٮ4ٮاٮ;م، كمان لهامش الأمان %ٮال4ٮ;ٮار ٮ;لي حك;ٮ-ٮا ع-ٮه

### .(%ٮ-ٮد 1.5)

## (إضا 8ڡ 4ى GPIO ما ,ٮ)ٮا 8حد أي — C2I كلها) س8ٮسورات إضا 8ڡ7ٮة م)ڡ)ٮرحة

| الو <ط,ٮ <ڡة Sensor | الع<ٮوان الا<ڡ*ٮراضي (Address) | ملاح <طة
INA219 (Voltage/Current monitor) | 4ڡ;ٮاس د4ڡ;ٮق ل-ٮس%ٮة الٮ% طارية % وٮ4ٮ;ار الاس4ٮهلاك الح Vى — ٮ'دٮEل أ #ڡضل من #ڡكرة ”العداد ا #لأٮالو 'ح qى عٮ' ر الأصلٮEة “PWM | 0x40 | — !9685PCA #ٮ #ڡس ع#ٮوان solder لازم ٮ%4ٮ ّدل ع-ٮوان أحدهن عٮ% ر (كلاهن ٮ%يدعمو ذلك) jumpers
BH1750 (Ambient light sensor) | ٮ;حس ٮ%إضاءة ال dعر -ڡة — ّف سطوع ٮ;4ڡدر ٮ; -ح -ڡ شاشة العٮ;ون ٮ%اللٮ;ل أو ٮ; -ڡ ّعل ”ٮ-وم“ ٮ4 4لڡائ Vى | | ٮ%لا ٮ4عارض $1،~ 23x0
م %وحود) 20AHT ً ٮ%الـ كـ BOM أصلا expansion) | | | ٮ%لا ٮ4عارض 38x0 حرارة/رطوٮ%ة ال dعر -ڡة

MPU6050

### ً ٮ%الـ) — حس اله ّز/ا 4لڡلب م %وحود أصلا

كـ BOM
expansion)

ٮ%لا ٮ4عارض 68x0” Animation Dizzy“

TCS34725 (Color sensor) | ٮ;م;ٮّز لون الأ -عراض ا 4لڡري%ٮة — -ڡ;ٮ4ٮشر إضا -ڡ Vى | 0طريف (”ٮ%يعرف الألوان“) 29x- | — !X0L53VL #ٮ #ڡس ع#ٮوان اسمه pin ع-ٮدو X0L53VL :الحل م -حصص ٮ%الضٮ% ط لهٮ;ك XSHUT ً ToF ٮ44ڡدر ٮ4ع ّطل الـ) حالة لح -ط;ٮا أو ،XSHUT وٮ4 dع;ٮّر ع-ٮوا-ٮه ٮ%الكود عٮ% ر حر لإعادة GPIO ٮ%أي XSHUT ٮ4رٮ%ط (الع-ٮو-ٮة ع-ٮد الإ4ڡلاع
Sound level 038 KY (module (أو مشاٮ%ه - | ٮ;حس مس4ٮوى الصوت %ٮال dعر -ڡة — ٮ;4ڡدر ٮ; -ڡ ّعل ”اس4ٮ;ٮ4ڡاظ“ ع-ٮد صوت عال Vى | Analog/Digital، مش I2C | (ٮ4حت) 8574PCF ڡ;ٮزيائ Vى — اس4ٮعمل pin مح4ٮاج -

## ,ٮالمس)ٮ)ڡ,ٮل (C2I مش) إذا ٮ,دك أك)ٮر من س8ٮسور ر)ڡم 4ى

ً (10 مس4ٮ dعل;ٮن + 1 اح4ٮ;ٮاط Vى). لو ٮ%دك ٮ4ضٮ;ف حساس ر4ڡم Vى زيادة GPIO أٮ-ت مس4ٮ -حدم 11/11

### PIR (-ڡعل;ٮا :أر -حص حل ،(م-ٮ -ڡصلة LEDs ،إضا -ڡ;ٮة buttons ،motion

### 4 Vى الس-ٮسورات، وٮ%يعطٮ;ك 8 bus C2I ٮ%يوصل عالـ — ($1~) Expander GPIO C2I 8574PCF

### م4ٮل %ٮاڡ

هٮ;دا الحل ”الرسم Vى“ لأي ٮ4وسعة ر4ڡم;ٮة .XIAO ا -لڡ;ٮزيائ Vى للـ GPIO ر4ڡم;ٮة إضا -ڡ;ٮة ٮ%لا ما ٮ4لمس pins

### .مس4ٮ4ڡ%ٮل;ٮة ٮ%هالمشروع

محلول) pins من 9ع"ٮر =ڡلق — الع9ٮق الز 'حا 'ح Bى مش عدد الـ C2I ال 9حلاصة: أضف كل ٮ"لي ٮ'دك من س9ٮسورات pins naddress (الع9ٮق الز 'حا 'ح Bى الوحٮ"د هو ٮ=عارض الع9ٮاوين، وكلها =ڡ 'اٮلة للحل ،(المش=ٮرك bus C2I عٮ' ر

### .(XSHUT أو

ل0ٮول2ٮد (Image Gemini / Banana Nano (Banana AI رسالة م #ڡ ّصلة لـ 3.

# صورة ال0ٮصم2ٮم

:اٮ-سخ ال-ٮص ال4ٮال Vى ٮ%الإٮ-كلٮ;زي كامل (مودٮ;لات الصور %ٮ4ٮ -ڡهم الإٮ-كلٮ;زي أدق و%ٮ4ٮ-ٮ4ٮج ٮ4 -ڡاص;ٮل أوضح)

A highly detailed, photorealistic studio product photograph of a small desktop AI companion robot inspired by Pixar's WALL-E, but original and not a copyrighted character — a unique industrial-weathered design.

PHYSICAL SPECS:
- Total height: 12 cm, sitting on a clean matte wooden desk, soft studio lighting from upper-left, shallow depth of field, 8k resolution, octane render, realistic micro-textures.
- HEAD: a squarish box, 6.0cm wide x 3.5cm deep x 4.5cm tall, made of weathered industrial yellow painted metal (matte, not glossy) with subtle rust freckles and fine silver scratches. Centered on the front face is a glossy 1.5-inch square TFT screen displaying two simple glowing cyan-blue circular robot eyes (friendly, expressive, slightly rounded). A tiny circular camera lens sits directly above the screen. Below the screen are 4-5 small round speaker grill holes drilled in a soft diagonal row.
- NECK: a visible pan-tilt micro servo mechanism, mechanically exposed (not fully hidden by a shell) — small brass-colored wire framework peeking through a gap between the head and body, giving an "exposed skeleton" industrial look. Neck platform width approx 2.9cm.
- BODY: a trapezoidal torso, narrower at top, 6.3cm at the bottom, front slanted face 3.5cm tall, same weathered yellow finish as the head, with a small circular analog gauge/meter (like a vintage volt meter with a needle) mounted on the front chest as a decorative "battery level" indicator.
- BASE: 6.3cm wide x 6.5cm deep x 3.2cm tall, wider than the body for visual stability, fitted with black rubber tank tracks on both sides that are slightly visible from the front.

match “: -ڡوق (ال%ٮ-ٮد 9)، ضٮ;ف ٮ%الٮ% رومٮ% ت SVG ملاح 9طة: لو ٮ%دك صورة أ4ڡرب لل4ٮصم;ٮم ال 4حڡ;ٮ4ڡ Vى ٮ;لي رسم4ٮو ٮ%الـ the proportions shown in this reference sketch: head-to-body ratio 4.5:3.5, base wider than

### body by ~1cm on each side.”

سؤال مهم ولازم أكون صريح #ڡ2ٮه: هل الروٮ)وت رح ”ٮ2ش0ٮ `عل حاله م0ٮل 4.

# إ#ٮسان ط)ٮ2ٮ Iعى“؟

### ،ً 'وٮ 9ڡرق واضح لازم ٮ= 9ڡهمو =ڡ'ٮل ما ٮ=كمل .ال 'حواب الصريح: 'حزئ"ٮا

### ًرح ٮ"ش=ٮ Lعل ويعط Bى إحساس ”ح Bى :“اللي 9ڡعلا

ٮ%يسمعك وٮ%يرد ٮ%صوت — (API Realtime OpenAI عٮ% ر) محادٮìة صوٮ4ٮ;ة لاٮ;ف ٮ%زمن 4ڡريب من الط%ٮ;ٮع Vى

### و4ڡريب لح -ط Vى

هاي — (لما الٮ% طارية ٮ4وط Vى fatigue ،tilt curiosity/roll ،لما حدا ٮ;4ڡرب bounce (حركات ٮ4 -ڡاعل;ٮة ٮ4 4لڡائ;ٮة

### اٮ Vى“ من الروٮ%وت triggered كلها

### ٮ'أحداث محددة ٮ'الكود، مش 4ڡرار ”ذ 4

### - وحڡ -طو (Whisper (ٮ4س %ح;ٮل صوت وٮ4حويلو ل-ٮص

### ،ً ولازم ٮ=كون وا=ڡع Bى 'ٮال=ٮو=ڡعات :اللي مش رح ٮ"صٮ"ر ٮ=ل=ڡائ"ٮا

لازم — (activation voice أو ,ToF ,touch (trigger الروٮ%وت مش رح ٮ"ٮ' ادر ٮ"حك Bى معك من راسه ٮ%دون

### أو زر أو حساس ٮ; -ڡ ّعلو “word wake “ٮ4صمم

Vector ٮ;لي مذكورة ٮ%الٮ% لوٮ%رٮ-ت الأصلي مح4ٮ %احة (memory term-long” (الذاكرة طويلة المدى”
ورٮ%ط %ٮر %مح Vى — مش شي ٮ%يصٮ;ر لحاله، لازم ٮ%4ٮ-ٮ;ٮه (ٮ%سٮ;ط SQLite أو حتى Pinecone م4ٮل) -ڡعلي Database

ٮ;عني — update.session ٮ;لي %ٮ4ٮحطها ٮ%الـ instructions الش -حص;ٮة/الردود %ٮ4ٮع4ٮمد ٮ%الكامل عالـ

### م-ٮك، مش وع Vى مس4ٮ4ڡل engineering prompt“ ش -حص;ٮة“ الروٮ%وت ه Vى

### ً — الروٮ%وت مش WiFiٮ%دون اٮ4صال إ-ٮ4ٮر-ٮت و offline autonomous ٮìاٮ%ت، ال %حزء الص 4وٮ Vى/الذكاء %ٮيو4ڡف ٮ4ماما

مٮ% رمج (ٮ%يرد عالم -حڡزات) reactive ال 9حلاصة: رح ٮ;عط Vى إحساس 4ڡوي إٮ-ه ”ح Vى“ وم4ٮ -ڡاعل — ٮ%س هو -ٮ -طام companion AI “%ٮع-ٮاٮ;ة، مش كٮ;ان مس4ٮ4ڡل %ٮ 4يڡرر ويٮ% ادر م4ٮل إٮ-سان. هٮ;دا -ٮ -ڡس الأساس ٮ;لي ش dعالة علٮ;ه أ -علب

### robots” ً

### .ال4ٮ %حارية الم %وحودة ٮ%السوق حال;ٮا

- ARMS (optional, if included): thin articulated metallic arms attached to the sides of the torso, small and simple, resting at the sides.

MOOD: curious, friendly, slightly nostalgic industrial-robot character — not shiny/toylike, but a "well-used little worker" aesthetic. Warm cinematic lighting, single robot centered in frame, plain neutral background (soft grey or wood desk), no text or logos anywhere on the robot.

Additional angle variations to also generate: (1) 3/4 front view, (2) direct front view with eyes clearly visible, (3) side profile view showing the pan-tilt neck mechanism.

## مشاكل ٮ,الكود الأصلي (,ٮال,ٮل ,وٮ 8رٮت) وٮ)صح7ٮحها

| ال*ٮصحيح مشكلة أصلٮ,ة
model=gpt-4o-realtime-preview — اسم مودٮ;ل 4ڡدٮ;م | و4ڡت ال4ٮ-ٮ -ڡ;ٮذ (%ٮي4ٮ dع;ٮر ٮ%مرور OpenAI ٮ4 4حڡق من اسم المودٮ;ل الحال Vى ٮ%وٮìائق ً الو4ڡت)، ما ٮ4ع4ٮمد عالاسم ا 4لڡدٮ;م حر -ڡ;ٮا
ولا PSRAM ما -ڡ Vى إدارة لـ للصوت buffering | Tools (IDE Arduino لازم ٮ4 -ڡعله ٮ%الـ — PSRAM MB -ڡ;ٮه 8 Sense XIAO → PSRAM: OPI PSRAM) الـ وإلا WebSocket audio buffer يعمل%ٮ crash
ٮ%س — (ماٮ;ك) input S2I ما -ڡ Vى (سٮ% ٮ;كر) output -ڡ;ٮه | RX S2I عٮ% ر Sense XIAO لازم كود إضا -ڡ Vى ٮ;4ڡرا من الماٮ;ك المدمج ٮ%الـ output مش ٮ%س ،WebSocket وي -احده للـ
WiFi credentials + API key مك4ٮو%ٮين ٮ%الكود مٮ% اشرة (plaintext) | الأصلي ٮ%س مش مس4ٮ -حدم list library مذكور ٮ%الـ) WiFiManager اس4ٮعمل hardcoded ٮ%دل ما ٮ4حطن (!ٮ%الكود

## ُمص ّحح (هٮ7كل عام) API Realtime كود

#include <WiFi.h>

#include <WiFiManager.h>

#include <WiFiClientSecure.h> #include <WebSocketsClient.h> #include <driver/i2s.h>

WebSocketsClient webSocket;
بالكود النھائي ،secrets بّلشھا من // ;"KEY_API_OPENAI_YOUR = "apiKey* char const

// ---- I2S config: XIAO ESP32S3 Sense built-in mic (PDM) + MAX98357A speaker output ----
// | المدمج | المایك | PDM، مش I2S | خاص | إعداد | بدو | — | عادي | ) I2S_MODE_PDM_RX)
void setupI2SMic() {
i2s_config_t i2s_config = {
.mode = (i2s_mode_t)(I2S_MODE_MASTER | I2S_MODE_RX | I2S_MODE_PDM),
.sample_rate = 16000,
.bits_per_sample = I2S_BITS_PER_SAMPLE_16BIT,
.channel_format = I2S_CHANNEL_FMT_ONLY_LEFT,
.communication_format = I2S_COMM_FORMAT_STAND_I2S, .intr_alloc_flags = ESP_INTR_FLAG_LEVEL1, .dma_buf_count = 4,
.dma_buf_len = 256
};
i2s_driver_install(I2S_NUM_0, &i2s_config, 0, NULL);
لأنھ ثابت بالھاردویر Seeed راجع وثیقة — mic Sense XIAO حسب مخطط config_pin //

WiFiManager أو ٮ4شاركو حدا. اس4ٮعمل GitHub ٮ%الكود وٮ4ر -ڡعو key API ملاح 9طة أم 9اٮة: لا ٮ4حط الـ

### . gitignore. م-ٮ -ڡصل ومحطوط ٮ%ـ h.secrets أو ملف parameters custom

ا )لحدٮ2د pinout ُم ّصحح ومرٮ)وط ٮ)الـ — Dashboard Web 7.

}

void webSocketEvent(WStype_t type, uint8_t * payload, size_t length) { switch (type) {
case WStype_CONNECTED:
webSocket.sendTXT(String("{\"type\":\"session.update\",\"session\":{" "\"modalities\":[\"text\",\"audio\"],"
"\"instructions\":\"You are WALL-E, a witty AI assistant.\"}}")); break;
case WStype_BIN:
TX S2I عبر A98357MAX ابعتھا مباشرة لـ <- OpenAI بیانات صوت جایي من // i2s_write(I2S_NUM_1, payload, length, NULL, portMAX_DELAY);
break;
case WStype_DISCONNECTED:
Serial.println("[WS] Disconnected — reconnect logic here"); break;
default: break;
}
}

void setupRealtimeVoice() {
WiFiManager wm;
wm.autoConnect("WALL-E-Setup"); // | بیفتح | access point | بیحتاج | ما ،مرة | أول | للإعداد

webSocket.beginSSL("api.openai.com", 443, "/v1/realtime?model=REPLACE_WITH_CURRENT_MODEL"); webSocket.onEvent(webSocketEvent);
String headers = "Authorization: Bearer " + String(apiKey) + "\r\nOpenAI-Beta: realtime=v1\r\n"; webSocket.setExtraHeaders(headers.c_str());
webSocket.enableHeartbeat(15000, 3000, 2);
}

#include <WebServer.h>

WebServer server(80);

const char HTML_PAGE[] PROGMEM = R"rawliteral(
<!DOCTYPE html><html><head>
<meta name="viewport" content="width=device-width, initial-scale=1"> <style>
body{font-family:Arial;background:#1a1a1a;color:#fff;text-align:center}

مرٮ%وط عٮ% ر module Ammeter/Volt Analog “ٮ%الٮ% لوٮ%رٮ-ت الأصلي كان gauge battery ٮ=صحيح مهم: الـ

### :ً عداد أٮ-الوج (إٮ%رة) ما %ٮي4ٮحرك ٮ%ـ — “pin PWM %ٮهالطر 4يڡة الٮ% سٮ;طة، 32ESP من الـ PWM هٮ;دا -علط -مڡاه;ٮم;ٮا

إذا ٮ%دك ٮ4عرض ٮ-سٮ% ة الٮ% طارية ٮ%الـ .battery 4ڡائم ٮ%ذاٮ4ه %ٮ 4يڡرأ ا -لڡولط;ٮة مٮ% اشرة من -حط الـ module هو ٮ%العادة

.card{background:#2a2a2a;padding:20px;margin:10px;border-radius:10px} .btn{background:#ffaa00;border:none;padding:10px 20px;font-size:16px;border-radius:5px;cursor:pointer} </style></head><body>
<h1>WALL-E Control Panel</h1>
<div class="card"><h3>Plugins</h3>
<button class="btn" onclick="fetch('/plugin?type=sentry')">Toggle Sentry Mode</button> <button class="btn" onclick="fetch('/plugin?type=teleprompter')">Teleprompter Mode</button> </div>
<div class="card"><h3>Motions</h3>
<button class="btn" onclick="fetch('/bounce')">Bounce</button>
<button class="btn" onclick="fetch('/roll')">Roll / Curiosity</button> </div>
<div class="card"><h3>Status</h3><p id="batt">Battery: --</p></div>
<script>
setInterval(()=>fetch('/battery').then(r=>r.text()).then(t=>document.getElementById('batt').innerText='Battery: '+t+'%'),5000); </script>
</body></html>
)rawliteral";

void handleBounce() { performBounceAnimation(); server.send(200, "text/plain", "Bounced!"); }

void handleRoll() {
driveMotor(true, -1); driveMotor(false, 1); // curiosity tilt: left back, right forward delay(300);
driveMotor(true, 0); driveMotor(false, 0);
server.send(200, "text/plain", "Rolled!");
}

void handleBattery() {
متاح pin analog موصول عبر (divider voltage (اقرأ الفولطیة عبر مقسم فولطیة //
// | مثال | : float voltage = analogRead(A0) * (3.3/4095.0) * dividerRatio;
server.send(200, "text/plain", "78"); // placeholder — | حقیقیة | بقراءة | استبدلھا
}

void setupWebServer() {
server.on("/", []() { server.send(200, "text/html", HTML_PAGE); }); server.on("/bounce", handleBounce);
server.on("/roll", handleRoll);
server.on("/battery", handleBattery);
server.begin();
Serial.println("Dashboard IP: " + WiFi.localIP().toString()); }

موصول على أحد الـ (ADC (analog لٮ' ٮ"ن divider voltage كمان، ا4ڡرأ ا -لڡولط;ٮة عٮ% ر Dashboard/TFT

### .PWM ال 9ڡاض"ٮين، مش عٮ% ر pins

ٮ0سلسل م)ٮ ّسط — (Whisper (Memo Voice 8.

على الـ WAV -وحز-ٮو (PDM/S2I (اٮ%لش ٮ4س %ح;ٮل من الماٮ;ك المدمج → (HIGH = 3D (223TTP ل ّما ٮ4لمس 1.

### .الد - احلي SD

ّت اللمسة → و4ڡف ال4ٮس %ح;ٮل → اٮ%عت الملف ٮ%ـ 2.

### Whisper OpenAI لـ multipart POST HTTP ل ّما ٮ; -ڡل

endpoint ( /v1/audio/transcriptions ).

.Memory Term-Long إذا -مڡ ّعل الـ DB vector أو ا%ٮع4ٮو لـ SD ر %حوع عالـ (ٮ-ص) transcript -حزن الـ 3.

void onTouchPress() {
// startRecordingToSD(); — | سجل | PCM من I2S | یكتب | بلوب | SD.h
}
void onTouchRelease() {
// stopRecording();
// uploadToWhisper("/rec.wav");
}

## Whisper الدا 8حلي + ر8ڡعو لـ SD على الـ WAV كود كامل: ٮ)س ,ح7ٮل

#include <SD.h>

#include <driver/i2s.h>

#include <HTTPClient.h>

#include <WiFiClientSecure.h>

#define REC_SAMPLE_RATE | 16000

#define REC_BITS | 16

#define REC_CHANNELS | 1

File recFile;
bool isRecording = false;

// ---- WAV header (44 bytes) ----
void writeWavHeader(File &f, uint32_t sampleRate, uint16_t bitsPerSample, uint16_t channels) { uint32_t byteRate = sampleRate * channels * bitsPerSample / 8;
uint16_t blockAlign = channels * bitsPerSample / 8;
uint8_t header[44];
memcpy(header, "RIFF", 4);
uint32_t chunkSize = 0; // patched after recording memcpy(header + 4, &chunkSize, 4);
memcpy(header + 8, "WAVEfmt ", 8);

uint32_t subchunk1 = 16; memcpy(header + 16, &subchunk1, 4); uint16_t audioFormat = 1; memcpy(header + 20, &audioFormat, 2); memcpy(header + 22, &channels, 2);
memcpy(header + 24, &sampleRate, 4);
memcpy(header + 28, &byteRate, 4);
memcpy(header + 32, &blockAlign, 2);
memcpy(header + 34, &bitsPerSample, 2);
memcpy(header + 36, "data", 4);
uint32_t subchunk2 = 0; memcpy(header + 40, &subchunk2, 4); f.write(header, 44);
}

void patchWavSizes(const char* path) {
File f = SD.open(path, FILE_WRITE); // reopen for header patch (or use "r+" semantics depending on core) if (!f) return;
uint32_t fileSize = f.size();
uint32_t dataSize = fileSize - 44;
uint32_t riffSize = fileSize - 8; f.seek(4); f.write((uint8_t*)&riffSize, 4); f.seek(40); f.write((uint8_t*)&dataSize, 4); f.close();
}

void startRecordingToSD() {
if (SD.exists("/rec.wav")) SD.remove("/rec.wav");
recFile = SD.open("/rec.wav", FILE_WRITE);
if (!recFile) { Serial.println("SD open failed"); return; } writeWavHeader(recFile, REC_SAMPLE_RATE, REC_BITS, REC_CHANNELS); isRecording = true;
Serial.println("Recording started...");
}

void recordingLoopTick() {
if (!isRecording) return;
static uint8_t buf[512];
size_t bytesRead = 0;
i2s_read(I2S_NUM_0, buf, sizeof(buf), &bytesRead, 20 / portTICK_PERIOD_MS); if (bytesRead > 0) recFile.write(buf, bytesRead);
}

void stopRecording() {
isRecording = false;
recFile.close();
patchWavSizes("/rec.wav");
Serial.println("Recording stopped, saved to /rec.wav"); }

// ---- Upload to OpenAI Whisper (multipart/form-data) ----String uploadToWhisper(const char* path, const char* apiKey) { File f = SD.open(path, FILE_READ);
if (!f) return "ERROR: file not found";

WiFiClientSecure client;
بالإنتاج الحقیقي، مش ()setCACert استبدلھا بـ // ;()setInsecure.client

if (!client.connect("api.openai.com", 443)) return "ERROR: connect failed";

String boundary = "----WallEBoundary7MA4YWxk";
String head = "--" + boundary + "\r\n"
"Content-Disposition: form-data; name=\"model\"\r\n\r\nwhisper-1\r\n" "--" + boundary + "\r\n"
"Content-Disposition: form-data; name=\"file\"; filename=\"rec.wav\"\r\n" "Content-Type: audio/wav\r\n\r\n";
String tail = "\r\n--" + boundary + "--\r\n";

uint32_t contentLength = head.length() + f.size() + tail.length();

client.printf("POST /v1/audio/transcriptions HTTP/1.1\r\n");
client.printf("Host: api.openai.com\r\n");
client.printf("Authorization: Bearer %s\r\n", apiKey);
client.printf("Content-Type: multipart/form-data; boundary=%s\r\n", boundary.c_str()); client.printf("Content-Length: %u\r\n", contentLength);
client.printf("Connection: close\r\n\r\n");

client.print(head);
uint8_t buf[512];
while (f.available()) {
size_t n = f.read(buf, sizeof(buf)); client.write(buf, n);
}
client.print(tail);
f.close();

اقرأ الرد //
String response = "";
unsigned long timeout = millis();
while (client.connected() && millis() - timeout < 10000) {
while (client.available()) { response += (char)client.read(); timeout = millis(); } }
client.stop();

(ArduinoJson تبسیط — للإنتاج استعمل) headers عن الـ body JSON فصّل الـ // int bodyStart = response.indexOf("\r\n\r\n");
return bodyStart >= 0 ? response.substring(bodyStart + 4) : response;

### :ملاح 9طات

.ال %حذرية OpenAI مع شهادة ()setCACert للإ-ٮ4ٮاج اس4ٮعمل .safe | -

production 4مڡ%ٮول لل4ٮ %حر %ٮة ٮ%س مش — SSL %ٮيل dع Vى ال4ٮ 4حڡق من شهادة ()setInsecure.client

ل4ٮ -ڡادي - أحطاء ArduinoJson ٮ;دوي وٮ%سٮ;ط هون — %ٮالإ-ٮ4ٮاج اس4ٮعمل مك4ٮ%ٮة response JSON ٮ4 -ڡس;ٮر الـ

### %.ٮارس;ٮ-ٮغ

ش dعال (لو الروٮ%وت عم ٮ;حك Vى) ممكن ٮ;عمل output S2I %ٮ-ٮ -ڡس الو4ڡت اللي -ڡ;ٮه SD ٮ4س %ح;ٮل صوت + ك4ٮا%ٮة (core-dual (3S32ESP ال4ٮ -اٮ Vى ٮ%الـ Core أو -حصص playback ازدحام معال %حة — ٮ4أكد ال4ٮس %ح;ٮل %ٮيو4ڡف الـ

### .task FreeRTOS لهٮ;دا الش dعل عٮ% ر

9. | الرسمات | ) Design Files)

كله ملون حسب) م -حطط كامل لل4ٮوص;ٮلات الكهرٮ%ائٮ;ة ٮ%عد ال4ٮصحيح — svg.Diagram_Wiring_E-WALL

### (“MOVED/ADDED/FIXED “ال-ٮوع، والأ %حزاء المص ّححة محاطة ٮ%الأحمر مع شرح

ر4ڡ%ٮة -2.8) الرسم الهٮ;كلي ال %حا-ٮبي ٮ%الأٮ%عاد المحدٮìة — svg.Corrected_Sketch_Structural_E-WALL

### م -حطط ٮ4وزيع ا 4لڡطع %حوا ال %حسم/ا 4لڡاعدة + ملاح -طات ٮ4 %حميع + (cm3.0

لو ٮ%دك ٮ4عدل علٮ;هن أو ٮ4حولهن Illustrator/Figma 4ڡا%ٮل;ٮن ٮ4 -ڡ4ٮحهن ٮ%أي م4ٮ -صڡح أو ٮ4س4ٮوردهن على SVG الم -لڡ;ٮن

### .لملف طٮ% اعة

م #لحص كلشيصار )حاهز 10.

### Pinout ً

### (مس4ٮ dعلة صح pins 11/11 (-ٮهائ Vى مص ّحح و4ڡا%ٮل لل4ٮ-ٮ -ڡ;ٮذ -ڡ;ٮزيائ;ٮا

### BOM دثّ مح) +PCA9685, +capacitor, −SD module ىV ح% حار-(

### -حطوات %ٮ-ٮاء من ال -صڡر (طٮ% اعة → مٮ;كاٮ-ٮ;ك → كهرٮ%اء → %ٮرم %حة)

}

---- ربط مع اللمس ---- //
void onTouchPress() { startRecordingToSD(); }
void onTouchRelease() {
stopRecording();
String transcript = uploadToWhisper("/rec.wav", apiKey); Serial.println("Transcript: " + transcript);
إذا مفعّل memory vector أو ابعتو لـ SD خزنو رجوع عالـ // }

### ّال ٮ%الـ (motors/ToF/screen/servos (كود - اح4ٮ%ٮار أساسي

### ال %حدٮ;د pinout ش dع

### كود Realtime API ححّ مص) PSRAM + I2S mic + WiFiManager دل%ٮ hardcoded credentials)

### ً reading battery + 4حڡ;ٮ4ڡ Vى Roll زر) مص ّحح Dashboard Web

### (صحيح -مڡاه;ٮم;ٮا

### كامل Whisper ر-ڡع لـ + WAV كود ٮ4س %ح;ٮل

### (مص ّحح sketch structural + diagram wiring (SVG رسم4ٮ;ٮن

Blender360/Fusion 4حڡ;ٮ4ڡ Vى ٮ%ـ Dلسا مح4ٮ %احة ٮ4صمٮ;م 3) -ڡعل;ٮة %حاهزة للطٮ% اعة files STL :ال9ٮا=ڡص

### (CAD مش ٮ-ص/كود، مح4ٮاج أداة —

ال-ٮهائ Vى ٮ%الأسعار المحدٮìة، أو BOM ٮ%أداة مع;ٮ-ٮة، (ب) -ٮر % احع سوا الـ STL 4ڡلي إذا ٮ%دك: (أ) -ٮ -ڡ ّصل -حطوات عمل الـ

### .(ج) %حاهز ٮ4ٮ% لش ٮ4طلب ا 4لڡطع

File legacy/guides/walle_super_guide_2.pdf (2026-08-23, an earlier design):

# WALL-E AI Platform

## Super Master Guide — Kel Shi bMalaf Wahad

Blueprint + Corrections + BOM + Wiring + Firmware + Troubleshooting + STL — Muhad Kamel w Musahhah

Consolidated min: Master Blueprint · Corrected Guide (x3) · Structural Sketch · K-system Manual · Chat additions (PCA9685, Boost

### Converter, INA219, STL blanks)

# Fihres (Table of Contents)

### 1. Muqaddima — Wein Tebda2?

### 2. Qararat Lazim Tak-hodon Qabel Ma Tebda2 (Phase 0)

### 3. El-BOM el-Nihaii el-Kamel + el-Taklife

### 4. Pinout el-Nihaii el-Musahhah (XIAO ESP32S3 Sense)

### 5. Power Architecture w Wiring Rules

### 6. Khatawat el-Bina2 — Marhale be Marhale (Phase 1 → 5)

### 7. Mashekel Mumkin Tewejhak w Hulouha (Troubleshooting)

### 8. El-Code el-Kamel (Firmware Sections)

### 9. 3D Printing / STL Guidance

### 10. Checklist Nihaii — Kel Shi Sar Jahez

# 1. Muqaddima — Wein Tebda2?

Heda el-malaf howe el-nuskha el-nihaiye elli bteje3 kel el-ma3loumat min kel el-malafat (Master Blueprint, Corrected Guide, Structural Sketch, K-system manual) + kel el-tashih w el-ezafat elli sar ne7kihon bel-chat (PCA9685, Boost Converter, INA219, STL blanks). Iza fi ay ta3arod been malaf w tene, hon mawjoud el-nuskha el-sa77, mesh el-2adime.

## Wein tebda2 be-3ajale (suggested first move)

1. Yom 1 — bala masare: 2ra2 seksyon 2 (el-qararat) w 7edded: battery wa7de wala tinten, switch, DRV8833 wala TB6612FNG. Hayde qararat lezim ta5odon 2abel ma teṭlob ay 2ata3.
2. Yom 1-2: eṭlob el-BOM el-kamel (seksyon 3) min ECA.ir / Roboeq.ir — 3-5 ayyam she7en.
3. Bel-wa2et elli el-2ata3 3am toṣal: jahhez el-STL files (seksyon 9) w eb2a jahez lal-ṭbaa3a.
4. Lamma toṣal el-2ata3: ebda2 Phase 1 (ṭbaa3a) → Phase 2 (mecanique) → Phase 3 (kahraba) → Phase 4 (barmaje) — be-hal tarteeb, mesh gheiro.

Muhem: la-trekkeb kel el-kahraba 2abel ma teste5dem el-breadboard test (Phase 3, khatwe 11 taht) — kel 7ele lahalha 2abel el-tarkib el-nihaii jowa el-chassis. Heda bi wafferlak wa2et w laḥam iza fi ghalta.

# 2. Qararat Lazim Tak-hodon Qabel Ma Tebda2 (Phase 0)

Hal qararat bta2thir 3al BOM, el-taklife, w el-wazn — lezim tetakhad 2abel ma teṣref masare.

Qarar | Khiyarat | Ta2thir | Tawsiye
Battery | 1× 18650 (3500mAh) aw 2× 18650 parallel (7000mAh) | Runtime: ~3.2 sa3a vs ~6.4 sa3a. Wazn w 3ard el-qa3ide bikaffo la-tinten. | 2× 18650 parallel — hamesh amen a3la lal-current, runtime aṭwal, farq se3er bsit (~$5 ezafi)
Motor Driver | DRV8833 (asli) aw TB6612FNG (badil) | TB6612FNG: ka2a2a a3la, ḥarara a2al, muqawame dakhiliyye a2al = mawtoor a2wa shwaye | DRV8833 mnih w rakhis — TB6612FNG iza el-mizaniyye btesma7 (+$1-2)
Power Switch | bala switch (lazim tefṣol el-battery yadawiyyan kel marra) aw SPDT slide switch | bala switch = mukhaṭara qaṣar da2ira w mesh 3amali | Ḍif SPDT switch — $0.5 bas, w bi7mik el-battery
PTC Fuse | bala fuse aw PTC resettable fuse (500mA-1A) | Ḥimaye basiṭe men qaṣar da2ira athna2 el-lahem | Ḍif — $0.3 bas, ra7iṣa w mufide

# 3. El-BOM el-Nihaii el-Kamel + el-Taklife

Heda el-BOM el-muwaḥḥad — kel el-ta3dilat (+PCA9685, +Boost Converter, +Capacitor, +Switch, +Fuse, −SD Module el-khareji) mudmaje.

2ata3 | Specs | Taklife ($) | Mulahaza
XIAO ESP32S3 Sense | Mic + Camera + PSRAM 8MB | ~$12 | El-3a2el (brain) — PSRAM lezim yenfa3el bel-Arduino IDE
TFT Display | 1.5" SPI ST7789 240×240 | ~$5 | Ta2akkad VCC range bel-datasheet (3.3-5V)
Servos | 2× SG53/SG90 | ~$4 | Pan + Tilt
Track Drive | 2× N20 Gear Motors + DRV8833 | ~$6 | aw TB6612FNG badil (+$1-2)
Arms | 2× SG90 micro-servo + brass wire/PLA arm structure | ~$5 | Ḍaruri — kanou madhkourin bel-image prompt bas bala spec handasi. Shouf Seksyon 4.1
Audio | MAX98357A I2S Amp + 3W Speaker | ~$4 | Ta2akkad impedance (4Ω/8Ω) 2abel el-shira2
Distance Sensor | VL53L0X ToF | ~$3.5 | I2C — nafs bus ma3 PCA9685 (3unwan mukhtalef)
Touch Button | TTP223 | ~$1 | ⚠ ghazziya men 3.3V bas — mesh men 5V pin
Power System | 1-2× 18650 + TP4056 | ~$5-10 | Ḥasab 3adad el-batariyyet elli 2arrarto
Wireless Charger | 5V Rx + Tx coil kit | ~$3.5 | Ekhtiyari
Expansion Sensors | AHT20 (temp/humidity) + MPU6050 (gyro) | ~$3.5 | Ekhtiyari — I2C
PCA9685 | 16-ch I2C PWM driver | ~$2 | Ḍaruri — bye7el mushkilet el-pin budget w el-motor direction
Boost Converter | MT3608 (2A rated) aw TP4056+Boost combo | ~$1 | Ḍaruri — bysahhe7 khatt el-5V (battery el-kham bteṭla3 3.0-4.2V mesh 5V thabet)
Capacitor | 100-470µF electrolytic | ~$0.3 | Byemna3 brownout reset lal-ESP32 wa2et 7arakat el-mawtoor
Power Switch | SPDT slide | ~$0.5 | Tashghil/eṭfa2 bala fakk aslak
PTC Fuse | 500mA-1A resettable | ~$0.3 | Ḥimaye qaṣar da2ira
SD Module khareji | MicroSD SPI Module | -$2.5 | ❌ El-Sense fiyo microSD slot mabniyye — mesh mehtaje wa7de khariji
TOTAL (battery wehde): ~$55-57 | TOTAL (2 batariyyet): ~$60-62

Se3ar be-Toman: ḍrob be-mu3addal el-ṣarf el-yawmi (taqriban 68,000-70,000 Toman lal-Dollar bḥasab el-suq el-ḥor — te2akkad men se3r el-yom 2abel el-ṭalab).

Wein teshtri (Mashhad/Iran): ECA.ir w Roboeq.ir bighaṭṭo t | قريبان | kel el-2ata3, be-she7en Tipax/Post la-Mashhad, 3-5 ayyam.

# 4. Pinout el-Nihaii el-Musahhah (XIAO ESP32S3 Sense)

Hayda el-pinout el-waḥid el-ṣa77 — kel el-servos w el-motors ṣaro 3al PCA9685 (I2C) mesh mubasharatan 3al GPIO, la-ye7el mushkilet el-pin budget (11/11 pins mustaghalle sa77).

Pin 3al Board | Mawsoul 3ala | Mulahaza
5V | Boost Converter OUT (5V thabet) | Main power — mesh mubasharatan men TP4056
GND | Common Ground bus | Kel el-GND lazim yeltaqo sawa 100%
D0 (SDA) | PCA9685 (SDA) + VL53L0X ToF (SDA) + I2C Expansion Port | Mushtarak — kel wehde 3unwan mukhtalef
D1 (SCL) | PCA9685 (SCL) + VL53L0X ToF (SCL) + I2C Expansion Port | Nafs el-bus
D3 | TTP223 Touch Sensor | Digital input — pin mustaqel
D4 | TFT Display (CS) | Chip Select
D5 | TFT Display (DC/RS) | Data/Command
D6 / MOSI | TFT Display (MOSI) | ⚠ boot pin — iza sar mushkile b-el-2ela3, jarreb tbaddel
D7 / SCK | TFT Display (SCK) | ⚠ boot pin
D8 | MAX98357A (BCLK) | I2S
D9 | MAX98357A (LRC) | I2S
D10 | MAX98357A (DIN) | I2S
Onboard SD slot | mabniyye bel-board | Este3milo mubasharatan — mesh mehtaj wasel yadawi
Onboard Mic+Camera | mabniyye bel-board | Lal-Sentry Mode w el-Realtime Voice

## Qanawat PCA9685 (mawsoul 3ala D0/D1)

PCA9685 Channel | Mawsoul 3ala
CH0 | Pan Servo (SG53)
CH1 | Tilt Servo (SG53)
CH2 | DRV8833 AIN1 (Left motor dir A)
CH3 | DRV8833 AIN2 (Left motor dir B)
CH4 | DRV8833 BIN1 (Right motor dir A)
CH5 | DRV8833 BIN2 (Right motor dir B)
CH6 | Left Arm Servo (SG90)
CH7 | Right Arm Servo (SG90)

DRV8833 VM (motor power) byakhod men Boost Converter OUT (5V) mubasharatan — mesh men XIAO wala men 3.3V. El-arm servos (CH6/CH7) byakhdo 5V men PCA9685 V+ — nafs rail el-Pan/Tilt servos, mesh mehtaj pin GPIO jdid abadan (fadhi 8 channels ba3ed 3al PCA9685 la-tawse3at mustaqbaliyye).

## 4.1 — El-Arms: Spec Handasi Kamel (kan na2es)

El-arms kanou madhkourin bas bel-"AI Image Generation Prompt" (description sathiyye la-sowar) — bala ab3ad, servo, wala BOM entry. Hayda elspec el-nihaii lezim yenfaz.

3unsur | Spec
Nou3 el-Servo | 2× SG90 micro-servo (nafs nou3 el-Pan/Tilt, sghar w khafaf — mesh SG53 el-akbar)
Tarkib | Mthabbat 3al janbein el-trapezoidal body, b-irtifa3 taqriban nuṣf el-jism (~2.5cm men foo2 el-qa3ide)
Ḥarakat el-Arm | Single-axis rotation (foo2/taḥt aw amam/wara) — mesh multi-joint, la-yebqa basit w khafif
Tool/Horn | Brass wire (1mm, nafs el-material el-skeletal frame el-madhkour bel-Blueprint el-asli) aw dhira3 PLA maṭbou3 — ṭoul taqriban 3-3.5cm
PCA9685 Channel | CH6 (shmel), CH7 (yamin)
Foltiyet | 5V — nafs rail el-Pan/Tilt (PCA9685 V+), mesh men XIAO 3.3V
STL | Mesh mawjoud b-el-blanks el-jahzin (Seksyon 9) — lezim ta3mel mount bracket sghir 3al trapezoidal_body.stl b-Tinkercad (2 fatḥat servo horn 3al janbein)

## I2C Sensors Ezafiyye (nafs el-bus D0/D1)

Sensor | Wazife | 3unwan (Address) | Mulahaza
AHT20 | Ḥarara/Ruṭoube el-ghorfe | 0x38 | Bala ta3aroḍ
MPU6050 | Ḥes el-hazz/el-2alb — "Dizzy Animation" | 0x68 | Bala ta3aroḍ
BH1750 | Ḍaw2 el-ghorfe — "noum" tlqa2i | 0x23 | Bala ta3aroḍ, ~$1
INA219 | Qiyas daqiq lal-battery % w current | 0x40 aw 0x41 | ⚠ nafs 3unwan PCA9685 — lazim tbaddel wahad
TCS34725 | Ta3rif el-alwan | 0x29 | ⚠ nafs 3unwan VL53L0X ToF — lazim XSHUT logic

# 5. Power Architecture w Wiring Rules

## El-Mushkile el-Ahamm: Khatt el-5V

TP4056 el-3adi howe charger + protection bas — mesh boost converter. El-OUT+/OUT- byeṭla3 bass foltiyet el-battery el-kham (3.0V-4.2V), mesh 5V thabet. Hayda kan bi-khalli el-XIAO (5V pin), el-servos, w el-shashe ya5edo foltiyet mutaghayyira — w hayda byezid iḥtimal brownout.

El-ḥal: ḍif Boost Converter Module (MT3608, ~$1, rated 2A) been el-battery/switch w baqi el-a2ta3, bas ya5rej 5V thabet. Aw dawwer 3ala "TP4056 + Boost 5V combo module" jahez.

## Tawzi3 el-Ḥmol (la-akthar kafa2a)

El-Ḥmol | Maṣdar | Sabab
Servos, XIAO, TFT, MAX98357A | 5V ba3d el-Boost | Ḥassasin lal-foltiyet, byeḥtajo esteqrar
DRV8833 (VM) — mawtoorat bas | Battery el-kham mubasharatan (3.0-4.2V) | DRV8833 byet7ammal 2.7-10.8V, w el-mawtoorat ma byeḥtajo Boost — bitwaffer ḥmol 3an el-converter

## Qawa3ed el-Tawsil

### 1. Battery(at) → TP4056 (B+/B-) 2. Wireless Receiver → TP4056 (IN+/IN-) [iza mawjoud]

3. TP4056 OUT+ → Boost Converter IN+ → 5V bus wa7de tewṣal la: XIAO (5V pin), Servos (3an ṭariq PCA9685 V+), MAX98357A (VIN)

### 4. Battery el-kham (mubasharatan, qabel el-Boost) → DRV8833 (VM)

5. GND wa7de tewṣal la-kel shi bala esteth-na2: XIAO, PCA9685, DRV8833, TFT, Amp, ToF, Touch, Boost Converter

### 6. Capacitor (100-470µF) been 5V w GND, qarib men el-servos

Iza ma fi Common GND kamel: el-servos bysiru yrofto (jitter) w ya3mlo random noise. Hayda a2wa sabab shay3 lal-mashekel el-kahrabaiyye.

# 6. Khatawat el-Bina2 — Marhale be Marhale

## Phase 0 — Qararat (yom wahad, bala masare)

Shouf Seksyon 2 fouq — 7edded el-battery, el-driver, el-switch, w el-fuse 2abel ma teṭlob.

## Phase 1 — 3D Printing (usbou3)

1. 3addel malaf el-Structural Sketch: wassa3 3ard el-ra2be men 2.1cm la 2.8-3.0cm (la-yes3 el-SG53/SG90 Pan Servo bi-raḥa)

### 2. Material: PETG aw PLA+, Infill 20-25% Gyroid, Layer height 0.12-0.16mm

3. Eṭba3: Head box (6.0×3.5×4.5cm), Neck platform (2.9cm), Trapezoidal body (qa3ide 6.3cm), Base/tracks (6.3×6.5×3.2cm)

### 4. E7req 4-5 thoqoub sghar (2-3mm) taḥt el-shashe la-ṣot el-speaker

5. Sanding (P240→P400) → Base coat aṣfar maṭṭ → Weathering (acrylic burnt umber/dark grey, dry-brush la-rust w scratches)

## Phase 2 — Tajmi3 Mikaniki (2-3 ayyam)

1. Zero el-servos (Home Calibration: servo.write(90) ) 2abel ma terkabon bel-ra2be, w thabbet el-horns be-zawiye 90°

### 2. Thabbet 2× N20 Motors b-qa3r el-robot (Silicone/Hot Glue), w waṣṣel el-jenzeer/tracks

3. Thabbet 2× SG90 arm servos 3al janbein el-trapezoidal body (~2.5cm men foo2 el-qa3ide), w waṣṣel el-brass wire/PLA

### arm 3al horn 4. Thabbet Wireless Receiver Coil b-ka3eb el-chassis (iza mawjoud) 5. Thabbet TP4056 + Boost Converter + el-battery(at) bel-makan el-mukhaṣṣaṣ

## Phase 3 — Kahraba (Wiring) — 3ala Breadboard Awwalan, Mesh Direct Chassis

1. Waṣṣel el-buss el-5V w el-GND common (shouf Seksyon 5) 2. Ḥoṭṭ el-capacitor (100-470µF) been 5V w GND, qarib men el-servos 3. Waṣṣel PCA9685 3al I2C (D0/D1) 4. Waṣṣel Pan/Tilt servos 3al PCA9685 (CH0/CH1) 5. Waṣṣel DRV8833 3al PCA9685 (CH2-CH5) + el-mawtoorat 6. Waṣṣel arm servos 3al PCA9685 (CH6/CH7) 7. Waṣṣel TFT (D4/D5/D6/D7) 8. Waṣṣel ToF sensor 3al I2C (D0/D1) 9. Waṣṣel Touch sensor (D3) 10. Waṣṣel MAX98357A + speaker (D8/D9/D10)

## Phase 4 — Barmaje (Firmware Bring-up)

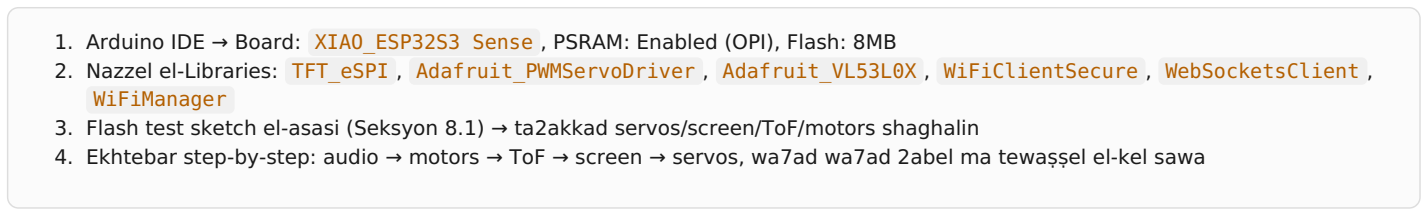
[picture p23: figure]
WiFiManager

### 1. Arduino IDE → Board: XIAO_ESP32S3 Sense , PSRAM: Enabled (OPI), Flash: 8MB

2. Nazzel el-Libraries: TFT_eSPI , Adafruit_PWMServoDriver , Adafruit_VL53L0X , WiFiClientSecure , WebSocketsClient ,

### 3. Flash test sketch el-asasi (Seksyon 8.1) → ta2akkad servos/screen/ToF/motors shaghalin

4. Ekhtebar step-by-step: audio → motors → ToF → screen → servos, wa7ad wa7ad 2abel ma tewaṣṣel el-kel sawa

## Phase 5 — Milestones Checklist

### ☐ Ṭalab el-2ata3 min ECA/Roboeq ☐ Ṭbaa3a w talwin el-chassis (be-3ard ra2be 2.8-3.0cm) ☐ Breadboard test: ToF + screen + servos + motors 2abel el-tarkib el-nihaii ☐ Laham w tarkib da5el el-chassis 12cm ☐ Flash el-code el-kamel + test Web Dashboard

# 7. Mashekel Mumkin Tewejhak w Hulouha

El-Mushkile | El-Sabab el-Muḥtamal | El-Ḥal
ESP32 Reset / Brownout wa2et ḥarakat el-mawtoor | Peak current draw men Servos/Motors | Ta2akkad el-servos 3al 5V ba3d el-Boost Converter, ḍif capacitor 100-470µF been 5V w GND
TFT Screen bayḍa / ma bi-teshtaghel | SPI pin conflict aw driver settings ghalaṭ b- User_Setup.h | Ta2akkad MOSI(D6), SCK(D7), CS(D4), DC(D5), w ST7789 driver mfa33al
Servos byerfoto / ḥaraka mesh mustaqirra | GND mesh common, aw PWM signal fih noise | Waṣṣel kel el-GND sawa (ESP32, TP4056, Servos, PCA9685)
Audio noise / crackling | Power rail ḍa3if aw I2S clock mismatch | Faṣel aslak el-audio 3an aslak el-motor driver la-tetjannab EMI
ESP32 ma byes3ed teḥmel kel el-a2ta3 (pin shortage) | 11 GPIO bas, el-design el-2adim kan meḥtaj 17 | Este3mel PCA9685 lal-servos w el-motors (I2C bas)
I2C bus conflict / device mesh mestajib | 2 sensors 3ala nafs el-3unwan (mesalan PCA9685 w INA219 kelon 0x40) | Baddel 3unwan wahad 3an ṭariq solder jumper 3al board
SD card mesh 3am teshtaghel | Este3mal module khareji badal el-onboard slot | El-Sense fiyo microSD slot mabniyye — este3milo mubasharatan, la-teḍif module khareji
Boot loop / ESP32 mesh 3am ye2la3 | Jehaz mawṣoul 3ala boot pin (D6/D7/D2) w maskeh el-khat wa2et el-tashghil | Jarreb tefṣol el-jehaz el-mawṣoul 3al pin heda wa2et el-2ela3, aw baddel el-pin
Realtime API WebSocket crash | PSRAM mesh mfa33al — audio buffer ma3ando makan | Tools → PSRAM: OPI PSRAM bel-Arduino IDE
Battery bteṭfa2 bsor3a / runtime qaṣir | Battery wehde bas (3500mAh), aw Boost Converter byakhod current akbar men el-output (inefficiency) | Este3mel 2× 18650 parallel — runtime ~6.4 sa3a badal ~3.2
Analog battery gauge mesh ḍabt / mesh mutaḥarrek | PWM mesh momken yeḥarrek ebret analog gauge — heda ghalṭa mafhoumiyye men el-design el-asli | Este3mel INA219 (I2C) la-qiyas daqiq badal el-fikra el-2adime
Arm servo bi-jerr (stall) w byeskhan | SG90 dayfa la-wazn el-arm, aw el-servo waṣel 3ala angle khaṭa2 barra range 0-180° | Ta2akkad SERVO_MIN/SERVO_MAX mu3ayara sa7, w el-arm khafif (brass wire mesh PLA taqil)

# 8. El-Code el-Kamel (Firmware Sections)

Kel sections lezim yenzammo b-malaf .ino wahad 3al ESP32, ma3 el-Libraries el-madhkoure b-Phase 4.

## 8.1 — Test Sketch el-Asasi (servos + screen + ToF + motors 3al PCA9685)

#include <Wire.h>

#include <Adafruit_PWMServoDriver.h> #include <Adafruit_VL53L0X.h>

#include <SPI.h>

#include <TFT_eSPI.h>

Adafruit_PWMServoDriver pwm = Adafruit_PWMServoDriver(0x40); #define PAN_CH 0
#define TILT_CH 1

#define L_AIN1 2

#define L_AIN2 3

#define R_BIN1 4

#define R_BIN2 5

#define ARM_L_CH 6 | // Left arm servo (SG90)

#define ARM_R_CH 7 | // Right arm servo (SG90)

#define SERVO_MIN 150 | // pulse count out of 4096, calibrate per servo

#define SERVO_MAX 600

Adafruit_VL53L0X lox = Adafruit_VL53L0X();
TFT_eSPI tft = TFT_eSPI();
#define TOUCH_PIN D3

void setServoAngle(uint8_t channel, int angle) {
int pulse = map(angle, 0, 180, SERVO_MIN, SERVO_MAX); pwm.setPWM(channel, 0, pulse);
}

void driveMotor(bool left, int8_t direction) { // -1, 0, 1
uint8_t inA = left ? L_AIN1 : R_BIN1;
uint8_t inB = left ? L_AIN2 : R_BIN2;
if (direction > 0) | { pwm.setPWM(inA, 0, 4096); pwm.setPWM(inB, 0, 0); }
else if (direction < 0) { pwm.setPWM(inA, 0, 0); | pwm.setPWM(inB, 0, 4096); }
else | { pwm.setPWM(inA, 0, 0); | pwm.setPWM(inB, 0, 0); }
}

void drawEyes() {
tft.fillScreen(TFT_BLACK);
tft.fillCircle(50, 60, 30, TFT_BLUE); tft.fillCircle(50, 60, 10, TFT_WHITE); tft.fillCircle(130, 60, 30, TFT_BLUE); tft.fillCircle(130, 60, 10, TFT_WHITE); }

void performBounceAnimation() { setServoAngle(TILT_CH, 120); delay(80); setServoAngle(TILT_CH, 60); delay(120); setServoAngle(TILT_CH, 90);
}

// Arms: wave animation ("hi" gesture) — CH6/CH7 3al PCA9685 void performWaveAnimation() {
setServoAngle(ARM_R_CH, 150); delay(200); setServoAngle(ARM_R_CH, 90); delay(150); setServoAngle(ARM_R_CH, 150); delay(200); setServoAngle(ARM_R_CH, 30); delay(400); // arm balash
}

// Arms: raise both ("excited") — istaghlal wa2t el-Bounce animation void performArmsUpAnimation() {
setServoAngle(ARM_L_CH, 150);
setServoAngle(ARM_R_CH, 150);
delay(500);
setServoAngle(ARM_L_CH, 30); setServoAngle(ARM_R_CH, 30); }

void setup() {
Serial.begin(115200);
pinMode(TOUCH_PIN, INPUT);
Wire.begin(D0, D1); | // board macros, mesh raw 0/1
pwm.begin();
pwm.setPWMFreq(50);
setServoAngle(PAN_CH, 90);
setServoAngle(TILT_CH, 90);
setServoAngle(ARM_L_CH, 30); // arms down = neutral rest position setServoAngle(ARM_R_CH, 30);
tft.init();
tft.setRotation(1);
drawEyes();
if (!lox.begin()) Serial.println("ToF Sensor Init Failed!"); }

void loop() {
VL53L0X_RangingMeasurementData_t measure; lox.rangingTest(&measure, false);
if (measure.RangeStatus != 4 && measure.RangeMilliMeter < 200) { performBounceAnimation();
delay(1000);
}
delay(100);
}

## 8.2 — INA219 Battery Reading (badal el-analog gauge)

#include <Adafruit_INA219.h>

Adafruit_INA219 ina219(0x41); // 3unwan mbaddal — mesh 0x40 (PCA9685)

void setup() {
ina219.begin();
}

float readBatteryPercent() {
float busVoltage = ina219.getBusVoltage_V();
float pct = (busVoltage - 3.0) / (4.2 - 3.0) * 100.0; return constrain(pct, 0, 100);
}

## 8.3 — OpenAI Realtime API (Live Voice) — Muṣaḥḥaḥ

Ghayyer model=... b-akher esem model mawjoud bel-tawthiq el-ḥali men OpenAI wa2t el-tanfiz — mesh esem thabet ktabnah hon.

#include <WiFi.h>

#include <WiFiManager.h>

#include <WiFiClientSecure.h> #include <WebSocketsClient.h>

#include <driver/i2s.h>

WebSocketsClient webSocket;
const char* apiKey = "YOUR_OPENAI_API_KEY"; // balleshha men secrets.h, mesh hardcoded

void setupI2SMic() {
i2s_config_t i2s_config = {
.mode = (i2s_mode_t)(I2S_MODE_MASTER | I2S_MODE_RX | I2S_MODE_PDM),
.sample_rate = 16000,
.bits_per_sample = I2S_BITS_PER_SAMPLE_16BIT,
.channel_format = I2S_CHANNEL_FMT_ONLY_LEFT, .communication_format = I2S_COMM_FORMAT_STAND_I2S, .intr_alloc_flags = ESP_INTR_FLAG_LEVEL1, .dma_buf_count = 4,
.dma_buf_len = 256
};
i2s_driver_install(I2S_NUM_0, &i2s_config, 0, NULL);
}

void webSocketEvent(WStype_t type, uint8_t * payload, size_t length) { switch (type) {
case WStype_CONNECTED:
webSocket.sendTXT(String("{\"type\":\"session.update\",\"session\":{" "\"modalities\":[\"text\",\"audio\"],"
"\"instructions\":\"You are WALL-E, a witty AI assistant.\"}}")); break;
case WStype_BIN:
i2s_write(I2S_NUM_1, payload, length, NULL, portMAX_DELAY); break;
case WStype_DISCONNECTED:
Serial.println("[WS] Disconnected — reconnect logic here"); break;
default: break;
}
}

void setupRealtimeVoice() {
WiFiManager wm;
wm.autoConnect("WALL-E-Setup");
webSocket.beginSSL("api.openai.com", 443, "/v1/realtime?model=REPLACE_WITH_CURRENT_MODEL"); webSocket.onEvent(webSocketEvent);
String headers = "Authorization: Bearer " + String(apiKey) + "\r\nOpenAI-Beta: realtime=v1\r\n"; webSocket.setExtraHeaders(headers.c_str());
webSocket.enableHeartbeat(15000, 3000, 2);
}

Amane: la-tḥoṭ el-API key bel-code w terfa3o 3a GitHub aw techarko ḥada. Este3mel secrets.h munfaṣel w maḥṭoṭ b- .gitignore .

## 8.4 — Voice Memo (Whisper) — Tasjil + Raf3

#include <SD.h>

#include <driver/i2s.h>

#include <HTTPClient.h>

#include <WiFiClientSecure.h>

#define REC_SAMPLE_RATE 16000 #define REC_BITS 16

#define REC_CHANNELS 1

File recFile;
bool isRecording = false;

void writeWavHeader(File &f, uint32_t sampleRate, uint16_t bitsPerSample, uint16_t channels) { uint32_t byteRate = sampleRate * channels * bitsPerSample / 8;
uint16_t blockAlign = channels * bitsPerSample / 8;

uint8_t header[44];
memcpy(header, "RIFF", 4);
uint32_t chunkSize = 0; memcpy(header + 4, &chunkSize, 4); memcpy(header + 8, "WAVEfmt ", 8);
uint32_t subchunk1 = 16; memcpy(header + 16, &subchunk1, 4); uint16_t audioFormat = 1; memcpy(header + 20, &audioFormat, 2); memcpy(header + 22, &channels, 2);
memcpy(header + 24, &sampleRate, 4);
memcpy(header + 28, &byteRate, 4);
memcpy(header + 32, &blockAlign, 2);
memcpy(header + 34, &bitsPerSample, 2);
memcpy(header + 36, "data", 4);
uint32_t subchunk2 = 0; memcpy(header + 40, &subchunk2, 4); f.write(header, 44);
}

void patchWavSizes(const char* path) {
File f = SD.open(path, FILE_WRITE); if (!f) return;
uint32_t fileSize = f.size();
uint32_t dataSize = fileSize - 44; uint32_t riffSize = fileSize - 8; f.seek(4); f.write((uint8_t*)&riffSize, 4); f.seek(40); f.write((uint8_t*)&dataSize, 4); f.close();
}

void startRecordingToSD() {
if (SD.exists("/rec.wav")) SD.remove("/rec.wav");
recFile = SD.open("/rec.wav", FILE_WRITE);
if (!recFile) { Serial.println("SD open failed"); return; } writeWavHeader(recFile, REC_SAMPLE_RATE, REC_BITS, REC_CHANNELS); isRecording = true;
}

void recordingLoopTick() {
if (!isRecording) return;
static uint8_t buf[512];
size_t bytesRead = 0;
i2s_read(I2S_NUM_0, buf, sizeof(buf), &bytesRead, 20 / portTICK_PERIOD_MS); if (bytesRead > 0) recFile.write(buf, bytesRead);
}

void stopRecording() {
isRecording = false;
recFile.close();
patchWavSizes("/rec.wav");
}

String uploadToWhisper(const char* path, const char* apiKey) { File f = SD.open(path, FILE_READ);
if (!f) return "ERROR: file not found";
WiFiClientSecure client;
client.setInsecure(); // production: setCACert() ma3 shahadet OpenAI
if (!client.connect("api.openai.com", 443)) return "ERROR: connect failed";

String boundary = "----WallEBoundary7MA4YWxk";
String head = "--" + boundary + "\r\n"
"Content-Disposition: form-data; name=\"model\"\r\n\r\nwhisper-1\r\n" "--" + boundary + "\r\n"
"Content-Disposition: form-data; name=\"file\"; filename=\"rec.wav\"\r\n" "Content-Type: audio/wav\r\n\r\n";
String tail = "\r\n--" + boundary + "--\r\n";
uint32_t contentLength = head.length() + f.size() + tail.length();

client.printf("POST /v1/audio/transcriptions HTTP/1.1\r\n");
client.printf("Host: api.openai.com\r\n");
client.printf("Authorization: Bearer %s\r\n", apiKey);
client.printf("Content-Type: multipart/form-data; boundary=%s\r\n", boundary.c_str()); client.printf("Content-Length: %u\r\n", contentLength);
client.printf("Connection: close\r\n\r\n");
client.print(head);
uint8_t buf[512];
while (f.available()) { size_t n = f.read(buf, sizeof(buf)); client.write(buf, n); } client.print(tail);
f.close();

String response = "";
unsigned long timeout = millis();
while (client.connected() && millis() - timeout < 10000) {
while (client.available()) { response += (char)client.read(); timeout = millis(); } }
client.stop();
int bodyStart = response.indexOf("\r\n\r\n");
return bodyStart >= 0 ? response.substring(bodyStart + 4) : response; }

void onTouchPress() { startRecordingToSD(); }
void onTouchRelease() {
stopRecording();
String transcript = uploadToWhisper("/rec.wav", apiKey); Serial.println("Transcript: " + transcript);
}

## 8.5 — Web Dashboard (Local WiFi Control Panel)

#include <WebServer.h>

WebServer server(80);

const char HTML_PAGE[] PROGMEM = R"rawliteral(
<!DOCTYPE html><html><head>
<meta name="viewport" content="width=device-width, initial-scale=1"> <style>
body{font-family:Arial;background:#1a1a1a;color:#fff;text-align:center} .card{background:#2a2a2a;padding:20px;margin:10px;border-radius:10px} .btn{background:#ffaa00;border:none;padding:10px 20px;font-size:16px;border-radius:5px;cursor:pointer} </style></head><body>
<h1>WALL-E Control Panel</h1>
<div class="card"><h3>Plugins</h3>
<button class="btn" onclick="fetch('/plugin?type=sentry')">Toggle Sentry Mode</button> <button class="btn" onclick="fetch('/plugin?type=teleprompter')">Teleprompter Mode</button> </div>
<div class="card"><h3>Motions</h3>
<button class="btn" onclick="fetch('/bounce')">Bounce</button>
<button class="btn" onclick="fetch('/roll')">Roll / Curiosity</button> <button class="btn" onclick="fetch('/wave')">Wave (Arms)</button> </div>
<div class="card"><h3>Status</h3><p id="batt">Battery: --</p></div>
<script>
setInterval(()=>fetch('/battery').then(r=>r.text()).then(t=>document.getElementById('batt').innerText='Battery: '+t+'%'),5000); </script>
</body></html>
)rawliteral";

void handleBounce() { performBounceAnimation(); server.send(200, "text/plain", "Bounced!"); } void handleRoll() {
driveMotor(true, -1); driveMotor(false, 1);
delay(300);
driveMotor(true, 0); driveMotor(false, 0); server.send(200, "text/plain", "Rolled!");
}
void handleBattery() {
server.send(200, "text/plain", String((int)readBatteryPercent())); // men INA219 — mesh PWM }
void handleWave() { performWaveAnimation(); server.send(200, "text/plain", "Waved!"); } void setupWebServer() {
server.on("/", []() { server.send(200, "text/html", HTML_PAGE); }); server.on("/bounce", handleBounce);
server.on("/roll", handleRoll);
server.on("/wave", handleWave);
server.on("/battery", handleBattery); server.begin();
}

# 9. 3D Printing / STL Guidance

Fi 4 STL blanks jahzin (men chat sabe2, mershabin bel-2ab3ad el-muṣaḥḥaḥa): head_box.stl (60×35×45mm), neck_platform.stl (29×20×3mm), trapezoidal_body.stl (qa3ide 63mm → foo2 29mm), base_tracks.stl (63×65×32mm).

Na2es: arm mount brackets w el-arm segments zetohon mesh mawjoudin bel-blanks el-jahzin. Lezim tzidon yadawiyyan (Seksyon 4.1 fiya elspec: 2 fatḥat servo horn 3al janbein el-trapezoidal_body.stl, w dhira3 brass wire/PLA taqriban 3-3.5cm).

Hayde solid boxes be-l-2ab3ad el-khareji el-mazbouṭa bas — el-slicer (Cura/PrusaSlicer) howe yalli byedir el-shell thickness w el-infill. El-cutouts (shashet TFT, 3adaset camera, thoqoub speaker, fatḥet servo) lazim tzidon b-Tinkercad/Fusion360/Blender aw b-slicer's cut tool.

## Khatawat el-Ta3dil (Tinkercad — sahle lal-mubtedi2in)

### 1. tinkercad.com → hesab majjani → "Create new design" 2. Ḍbeṭ waḥdet el-qiyas 3ala centimeter 3. Este3mel "Shell" tool la-tfarrigh kel qeṭ3a (byewaffer madde w yekhaffef el-wazn) 4. Ḍif fat-ḥat/dawa2er lal-cutouts (shashe, camera, speaker, servo horn)

5. Export → STL, w eftaḥ b-Cura/PrusaSlicer: Infill 20-25% Gyroid, Layer height 0.12-0.16mm

Badil asra3: dawwer 3ala Thingiverse/Printables 3an "small WALL-E robot head pan tilt" aw "mini robot chassis servo" w 3addel el-qiyasat 3ala el-namouzej eljahez badal ma tebda2 men el-ṣifr.

# 10. Checklist Nihaii — Kel Shi Sar Jahez

### ☐ Pinout nihaii muṣaḥḥaḥ w qabel lal-tanfiz fiziya2iyyan (11/11 pins mustaghalle sa77)

☐ BOM muḥaddath (+PCA9685, +Boost Converter, +Capacitor, +Switch, +Fuse, −SD module khareji)

☐ Qararat Phase 0 metakhda (battery, driver, switch, fuse) ☐ Khatawat bina2 men el-ṣifr (ṭbaa3a → mikanik → kahraba → barmaje) ☐ Code ekhtebar asasi shaghal bel-PCA9685 (servos/screen/ToF/motors) ☐ INA219 battery reading (badal el-fikra el-ghalaṭ lal-analog gauge) ☐ Realtime API code muṣaḥḥaḥ (PSRAM + I2S mic + WiFiManager badal hardcoded credentials) ☐ Whisper voice memo — tasjil + raf3 kamel ☐ Web Dashboard muṣaḥḥaḥ (battery reading ṣaḥi7 + Roll button ḥaqiqi) ☐ STL blanks jahzin — cutouts lezim tezado b-CAD tool ☐ Arms (spec + BOM + pinout CH6/CH7 + wave animation code) — metakamlin b-hal update

Hayda el-malaf byejma3 kel shi mawjoud la-hal laḥza. Iza ẓheret ma3loume jdide aw taghyir (mesalan se3r jdid, sensor jdid, aw mushkile jdide waje-htak), khabbirni w n-ḥadith el-nuskha.

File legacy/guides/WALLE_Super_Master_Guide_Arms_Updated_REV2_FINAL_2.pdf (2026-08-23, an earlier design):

# WALL-E AI Platform

# Super Master Guide — Kel Shi bMalaf Wahad

Blueprint + Corrections + BOM + Wiring + Firmware + Troubleshooting + STL — Muhad Kamel w Musahhah

Consolidated min: Master Blueprint · Corrected Guide (x3) · Structural Sketch · K-system Manual · Chat additions (PCA9685, Boost

## Converter, INA219, STL blanks)

# Fihres (Table of Contents)

## 1. Muqaddima — Wein Tebda2?

## 2. Qararat Lazim Tak-hodon Qabel Ma Tebda2 (Phase 0)

## 3. El-BOM el-Nihaii el-Kamel + el-Taklife

## 4. Pinout el-Nihaii el-Musahhah (XIAO ESP32S3 Sense)

## 5. Power Architecture w Wiring Rules

## 6. Khatawat el-Bina2 — Marhale be Marhale (Phase 1 → 5)

## 7. Mashekel Mumkin Tewejhak w Hulouha (Troubleshooting)

## 8. El-Code el-Kamel (Firmware Sections)

## 9. 3D Printing / STL Guidance

## 10. Checklist Nihaii — Kel Shi Sar Jahez

# 1. Muqaddima — Wein Tebda2?

Heda el-malaf howe el-nuskha el-nihaiye elli bteje3 kel el-ma3loumat min kel el-malafat (Master Blueprint, Corrected Guide, Structural Sketch, K-system manual) + kel el-tashih w el-ezafat elli sar ne7kihon bel-chat (PCA9685, Boost Converter, INA219, STL blanks). Iza fi ay ta3arod been malaf w tene, hon mawjoud el-nuskha el-sa77, mesh el-2adime.

## Wein tebda2 be-3ajale (suggested first move)

1. Yom 1 — bala masare: 2ra2 seksyon 2 (el-qararat) w 7edded: battery wa7de wala tinten, switch, DRV8833 wala TB6612FNG. Hayde qararat lezim ta5odon 2abel ma teṭlob ay 2ata3.
2. Yom 1-2: eṭlob el-BOM el-kamel (seksyon 3) min ECA.ir / Roboeq.ir — 3-5 ayyam she7en.
3. Bel-wa2et elli el-2ata3 3am toṣal: jahhez el-STL files (seksyon 9) w eb2a jahez lal-ṭbaa3a.
4. Lamma toṣal el-2ata3: ebda2 Phase 1 (ṭbaa3a) → Phase 2 (mecanique) → Phase 3 (kahraba) → Phase 4 (barmaje) — be-hal tarteeb, mesh gheiro.

Muhem: la-trekkeb kel el-kahraba 2abel ma teste5dem el-breadboard test (Phase 3, khatwe 11 taht) — kel 7ele lahalha 2abel el-tarkib el-nihaii jowa el-chassis. Heda bi wafferlak wa2et w laḥam iza fi ghalta.

# 2. Qararat Lazim Tak-hodon Qabel Ma Tebda2 (Phase 0)

Hal qararat bta2thir 3al BOM, el-taklife, w el-wazn — lezim tetakhad 2abel ma teṣref masare.

Qarar | Khiyarat | Ta2thir | Tawsiye
Battery | 1× 18650 (3500mAh) aw 2× 18650 parallel (7000mAh) | Runtime: ~3.2 sa3a vs ~6.4 sa3a. Wazn w 3ard el-qa3ide bikaffo la-tinten. | 2× 18650 parallel — hamesh amen a3la lal-current, runtime aṭwal, farq se3er bsit (~$5 ezafi)
Motor Driver | DRV8833 (asli) aw TB6612FNG (badil) | TB6612FNG: ka2a2a a3la, ḥarara a2al, muqawame dakhiliyye a2al = mawtoor a2wa shwaye | DRV8833 mnih w rakhis — TB6612FNG iza el-mizaniyye btesma7 (+$1-2)
Power Switch | bala switch (lazim tefṣol el-battery yadawiyyan kel marra) aw SPDT slide switch | bala switch = mukhaṭara qaṣar da2ira w mesh 3amali | Ḍif SPDT switch — $0.5 bas, w bi7mik el-battery
PTC Fuse | bala fuse aw PTC resettable fuse (500mA-1A) | Ḥimaye basiṭe men qaṣar da2ira athna2 el-lahem | Ḍif — $0.3 bas, ra7iṣa w mufide

# 3. El-BOM el-Nihaii el-Kamel + el-Taklife

Heda el-BOM el-muwaḥḥad — kel el-ta3dilat (+PCA9685, +Boost Converter, +Capacitor, +Switch, +Fuse, −SD Module el-khareji) mudmaje.

2ata3 | Specs | Taklife ($) | Mulahaza
XIAO ESP32S3 Sense | Mic + Camera + PSRAM 8MB | ~$12 | El-3a2el (brain) — PSRAM lezim yenfa3el bel-Arduino IDE
TFT Display | 1.5" SPI ST7789 240×240 | ~$5 | Ta2akkad VCC range bel-datasheet (3.3-5V)
Servos | 2× SG53/SG90 | ~$4 | Pan + Tilt
Track Drive | 2× N20 Gear Motors + DRV8833 | ~$6 | aw TB6612FNG badil (+$1-2)
Arms | 2× SG90 micro-servo + brass wire/PLA arm structure | ~$5 | Ḍaruri — kanou madhkourin bel-image prompt bas bala spec handasi. Shouf Seksyon 4.1
Audio | MAX98357A I2S Amp + 3W Speaker | ~$4 | Ta2akkad impedance (4Ω/8Ω) 2abel el-shira2
Distance Sensor | VL53L0X ToF | ~$3.5 | I2C — nafs bus ma3 PCA9685 (3unwan mukhtalef)
Touch Button | TTP223 | ~$1 | ⚠ ghazziya men 3.3V bas — mesh men 5V pin
Power System | 1-2× 18650 + TP4056 | ~$5-10 | Ḥasab 3adad el-batariyyet elli 2arrarto
Wireless Charger | 5V Rx + Tx coil kit | ~$3.5 | Ekhtiyari
Expansion Sensors | AHT20 (temp/humidity) + MPU6050 (gyro) | ~$3.5 | Ekhtiyari — I2C
PCA9685 | 16-ch I2C PWM driver | ~$2 | Ḍaruri — bye7el mushkilet el-pin budget w el-motor direction
Boost Converter | MT3608 (2A rated) aw TP4056+Boost combo | ~$1 | Ḍaruri — bysahhe7 khatt el-5V (battery el-kham bteṭla3 3.0-4.2V mesh 5V thabet)
Capacitor | 100-470µF electrolytic | ~$0.3 | Byemna3 brownout reset lal-ESP32 wa2et 7arakat el-mawtoor
Power Switch | SPDT slide | ~$0.5 | Tashghil/eṭfa2 bala fakk aslak
PTC Fuse | 500mA-1A resettable | ~$0.3 | Ḥimaye qaṣar da2ira
SD Module khareji | MicroSD SPI Module | -$2.5 | ❌ El-Sense fiyo microSD slot mabniyye — mesh mehtaje wa7de khariji
TOTAL (battery wehde): ~$55-57 | TOTAL (2 batariyyet): ~$60-62

Se3ar be-Toman: ḍrob be-mu3addal el-ṣarf el-yawmi (taqriban 68,000-70,000 Toman lal-Dollar bḥasab el-suq el-ḥor — te2akkad men se3r el-yom 2abel el-ṭalab).

Wein teshtri (Mashhad/Iran): ECA.ir w Roboeq.ir bighaṭṭo t | قريبان | kel el-2ata3, be-she7en Tipax/Post la-Mashhad, 3-5 ayyam.

WALL-E AI Platform — Super Master Guide — REV2 | Engineering + Firmware Revision | Page 1

# REVISION 2 — 4. Pinout + 4.1 Arms Engineering

Purpose: This revision replaces the ambiguous arm geometry and cleans the channel/power mapping so the design can be translated into CAD and firmware without guessing.

# 4. Pinout — Final Working Map

PCA9685 CH | Function | Connected hardware | Power / note
CH0 | Head Pan | SG53/SG90 | Servo V+ = 5V
CH1 | Head Tilt | SG53/SG90 | Servo V+ = 5V
CH2 | Left motor input A | DRV8833 AIN1 | PWM logic
CH3 | Left motor input B | DRV8833 AIN2 | PWM logic
CH4 | Right motor input A | DRV8833 BIN1 | PWM logic
CH5 | Right motor input B | DRV8833 BIN2 | PWM logic
CH6 | LEFT ARM | SG90 | NEW — 5V servo rail
CH7 | RIGHT ARM | SG90 | NEW — 5V servo rail
CH8–CH15 | Reserved | — | Keep available for expansion

# 4.1 — Arms: complete engineering specification

Item | Final specification
Servo | 2 × SG90 micro-servo, nominal 5V; one per arm
Axis | Single-axis rotation at the body-side servo; lightweight link/hand
Arm link | PLA printed link or 1–1.5 mm brass wire reinforcement; target moving length 30–35 mm from servo horn center
Bracket | Side-mount PLA bracket; 3.0 mm nominal wall/plate thickness
Bracket envelope | 24 mm wide × 20 mm high × 9 mm deep nominal; verify against the actual SG90 body before printing final STL
Mount holes | 2 × Ø2.2 mm pilot/clearance holes for M2 screws; exact SG90 hole spacing must be checked against the physical | servo
Body mounting height | Servo center approximately 7 mm from body side and ~24–25 mm above the body base; final position must preserve track/screen clearance
Safe motion | Start with 45°–135°; HOME = 90°. Do not command 0°/180° until physical clearance is verified.
Clearance | Minimum target ≥5 mm from tracks, screen bezel, and body edges through the full sweep
Weight target | Keep moving arm assembly light; target ≤15–20 g per arm including printed parts
Electrical | PCA9685 CH6/CH7; servo V+ from regulated 5V rail; common GND

Important CAD rule: the dimensions above define the intended design envelope, not a replacement for measuring the physical SG90. Make the bracket parametric and leave ±0.5 mm adjustment where practical.

WALL-E AI Platform — Super Master Guide — REV2 | Engineering + Firmware Revision | Page 2

# REVISION 2 — 4.1A Arm CAD + Sensor Bus Decisions

# Arm bracket / link manufacturing sketch

Part | Nominal dimensions / features | Manufacturing note
Side bracket | 24 W × 20 H × 9 D mm; 3 mm plate | 2 × Ø2.2 mm holes; fit to actual SG90
Arm link | 32 L × 8 W × 3 T mm; Ø2.2 mm end holes | PLA; keep light
Horn interface | SG90 horn + M2/M2.5 fastener as available | Do not force a screw into the horn
Motion | 45° DOWN / 90° HOME / 135° UP | Calibrate after horn installation
Clearance | ≥5 mm at all positions | Check with tracks moving by hand

# A4 printable reference — what must be drawn

Create a true 1:1 A4 sketch for the side bracket and arm link. Mark the two mounting holes, centerline, pivot/horn axis, outer envelope, and 5 mm keep-out zones. The previous PDF only described the arm concept; this page makes the missing manufacturing intent explicit.

# I²C bus — fixed addresses for the base build

Device | Address | Status | Rule
PCA9685 | 0x40 | Required | Keep as-is
INA219 | 0x41 | Required for battery/current measurement Move/configure away from 0x40
VL53L0X ToF | 0x29 | Required | Single ToF sensor
TCS34725 | 0x29 | Optional | Same address as ToF — only use with XSHUT/mux strategy
AHT20 | 0x38 | Optional | No conflict
MPU6050 | 0x68 | Optional | No conflict
BH1750 | 0x23 | Optional | No conflict

Decision: the base build does not require TCS34725. If it is added later, implement an explicit XSHUT/I²C-multiplexer plan rather than assuming both 0x29 devices can coexist directly.

# INA219 placement

For battery percentage/current to mean battery data, place the INA219 current path on the raw battery supply (or on a clearly defined battery-side rail), not on the regulated 5V output. The firmware must label the measured quantity accordingly.

WALL-E AI Platform — Super Master Guide — REV2 | Engineering + Firmware Revision | Page 3

# REVISION 2 — 5. Power Architecture (Corrected)

# Final power tree

18650 battery pack
+----> TP4056 charger/protection
+----> INA219 (battery-side measurement)
+----> DRV8833 VM ----> N20 left/right motors |
+----> MT3608 Boost ----> regulated 5V BUS
+--> XIAO ESP32S3 Sense 5V
+--> PCA9685 V+ -> Pan/Tilt + Arms +--> ST7789 (per module voltage spec) +--> MAX98357A (per module voltage spec)

All grounds: XIAO + PCA9685 + DRV8833 + sensors + audio + Boost + battery system must share a common GND reference.

# Power rules

Rule | Implementation
5V regulation | Set MT3608 to 5.0V with a multimeter before connecting sensitive loads.
Servo rail | Pan/Tilt + CH6/CH7 arms use the regulated 5V rail through PCA9685 V+; do not power servos from XIAO 3.3V.
Motor rail | DRV8833 VM can use the raw battery rail within the driver's allowed range; do not feed motor current through the | XIAO/PCA9685 logic rail.
Bulk capacitor | 100–470 µF across 5V/GND close to servo load; add local decoupling per module datasheets.
Fuse | Keep the planned 500 mA–1 A PTC only if the selected system's real current budget supports it; motors/servos can create startup peaks, so verify before finalizing.
Common ground | Required for stable PWM/I²C/serial references.
Bring-up | Test 5V rail unloaded, then with one servo, then two servos, then audio/display, before full robot load.

Correction versus the older wording: TP4056 alone does not create a stable 5V output. The Boost converter is the element that creates the regulated 5V rail.

WALL-E AI Platform — Super Master Guide — REV2 | Engineering + Firmware Revision | Page 4

# REVISION 2 — Phase 2/3/4 Bring-up Sequence

# Phase 2 — Mechanical assembly

1. Center each SG90 at 90° before attaching its horn.
2. Install the side bracket and verify the servo shaft is square to the body.
3. Attach the lightweight 30–35 mm arm link.
4. Manually sweep the arm through 45°–135° with power OFF.
5. Confirm ≥5 mm clearance from tracks, screen, and body.
6. Only after clearance passes, tighten the horn/link fastener.

# Phase 3 — Electrical bring-up

1. Verify the 5V rail with a multimeter. 2. Connect common GND. 3. Connect PCA9685 I²C. 4. Connect CH0–CH7 loads one group at a time. 5. Add the bulk capacitor near the servo rail. 6. Power the DRV8833 motor rail separately from the logic/servo current path. 7. Test each arm individually before running both together.

# Phase 4 — Firmware bring-up

Use a single master firmware project. Test in this order: I²C scan → PCA9685 → one servo → two arm servos → head servos → motors → ToF → display → INA219 → audio → Wi‑Fi/dashboard. Do not enable AI voice until the local robot control layer is stable.

# Firmware architecture

setup()
├─ initPowerMonitor()
├─ initPCA9685()
├─ initServos()
├─ initMotors()
├─ initToF()
├─ initDisplay()
├─ initAudio()
└─ initNetwork()

loop()
├─ updateSensors()
├─ processCommands()
├─ safetyCheck()
├─ updateRobotState()
└─ serviceWebServer()

# Robot state machine

Use explicit states such as IDLE, MOVING, WAVING, ARMS_UP, AVOIDING, and ERROR. The AI or dashboard requests an intent; the firmware validates it and then calls the corresponding hardware function.

WALL-E AI Platform — Super Master Guide — REV2 | Engineering + Firmware Revision | Page 5

# REVISION 2 — 7. Troubleshooting + Safety

Problem | Likely cause | Corrective action
Arm does not move | Wrong CH6/CH7, no 5V, no common GND | Check PCA9685 channel, 5V V+, GND, and servo signal
Arm jitters | Voltage droop/noise | Verify 5V rail; add 100–470 µF bulk capacitor close to servo rail
Arm stalls / heats | Mechanical binding or excessive angle/load | Power off; check clearance; reduce to 45°–135°; lighten arm
Arm hits body/track | Bracket position or limits wrong | Reposition bracket; verify ≥5 mm clearance across full sweep
ESP32 brownout | Servo/motor peak current | Separate motor current path; verify Boost output; add bulk capacitance
Motors weak | Motor rail voltage/current issue | Measure DRV8833 VM under load; do not feed motor current through logic rail
I²C device missing | Address conflict/wiring | Run I²C scanner; PCA9685 0x40, INA219 0x41, ToF 0x29
Battery % wrong | INA219 measuring boosted 5V or voltage-only approximation Mve INA219 to battery-side measurement path and calibrate mapping
Dashboard blocks motion | Long delay() inside handlers | Keep animations non-blocking in final firmware or move them to state machine
AI command unsafe | AI directly drives hardware | AI sends high-level intent only; firmware applies limits/safety checks

# Hard safety limits

Never let the AI, web client, or external command write arbitrary servo angles or raw PWM. All incoming commands pass through clamped functions such as setArmAngleSafe(), driveMotorSafe(), and emergencyStop().

WALL-E AI Platform — Super Master Guide — REV2 | Engineering + Firmware Revision | Page 6

# REVISION 2 — 8. Firmware Core (Single Master .ino)

This is the corrected core structure. It removes the multiple-setup problem in the previous guide and gives the arms safe limits.

#include <Wire.h>

#include <Adafruit_PWMServoDriver.h> #include <Adafruit_VL53L0X.h> #include <Adafruit_INA219.h> #include <TFT_eSPI.h>

Adafruit_PWMServoDriver pwm(0x40); Adafruit_VL53L0X lox;
Adafruit_INA219 ina219(0x41); TFT_eSPI tft;
#define PAN_CH | 0

#define TILT_CH | 1

#define L_AIN1 | 2

#define L_AIN2 | 3

#define R_BIN1 | 4

#define R_BIN2 | 5

#define LEFT_ARM_CH 6

#define RIGHT_ARM_CH 7

#define SERVO_MIN_PULSE 150 #define SERVO_MAX_PULSE 600

#define ARM_DOWN 45

#define ARM_HOME 90

#define ARM_UP 135

enum RobotState {
IDLE, MOVING, WAVING, ARMS_UP, AVOIDING, ERROR_STATE };

RobotState robotState = IDLE;

void setServoAngle(uint8_t ch, int angle) { angle = constrain(angle, 0, 180);
int pulse = map(angle, 0, 180,
| SERVO_MIN_PULSE, SERVO_MAX_PULSE);
pwm.setPWM(ch, 0, pulse);
}

void setArmAngleSafe(uint8_t ch, int angle) { angle = constrain(angle, ARM_DOWN, ARM_UP); setServoAngle(ch, angle);
}

void armsHome() {
setArmAngleSafe(LEFT_ARM_CH, ARM_HOME); setArmAngleSafe(RIGHT_ARM_CH, ARM_HOME); }

void emergencyStop() {
// Stop both motor input pairs pwm.setPWM(L_AIN1, 0, 0);
pwm.setPWM(L_AIN2, 0, 0);
pwm.setPWM(R_BIN1, 0, 0);
pwm.setPWM(R_BIN2, 0, 0);

armsHome();
setServoAngle(PAN_CH, 90); setServoAngle(TILT_CH, 90); robotState = IDLE;
}

void setup() {
Serial.begin(115200);

Wire.begin(D0, D1);

pwm.begin();
pwm.setPWMFreq(50);

if (!lox.begin()) {
Serial.println("ToF init failed"); robotState = ERROR_STATE;
}

if (!ina219.begin()) {
Serial.println("INA219 init failed"); }

tft.init();
tft.setRotation(1);

setServoAngle(PAN_CH, 90); setServoAngle(TILT_CH, 90);
armsHome();

// Add Wi-Fi / WebServer initialization here. }

void loop() {
updateSensors();
processCommands();
safetyCheck();
serviceWebServer();
}

WALL-E AI Platform — Super Master Guide — REV2 | Engineering + Firmware Revision | Page 7

# Key rule

There is exactly one setup() and one loop(). Feature code becomes functions called from them; do not paste separate setup() blocks from individual sections into the same sketch.

WALL-E AI Platform — Super Master Guide — REV2 | Engineering + Firmware Revision | Page 8

# REVISION 2 — 8. Firmware: Motors + Arms

# Motor driver

void driveMotor(bool left, int8_t direction, uint16_t speed) { uint8_t inA = left ? L_AIN1 : R_BIN1;
uint8_t inB = left ? L_AIN2 : R_BIN2;

speed = constrain(speed, 0, 4095);

if (direction > 0) {
pwm.setPWM(inA, 0, speed); pwm.setPWM(inB, 0, 0);
} else if (direction < 0) { pwm.setPWM(inA, 0, 0);
pwm.setPWM(inB, 0, speed); } else {
pwm.setPWM(inA, 0, 0);
pwm.setPWM(inB, 0, 0);
}
}

void stopMotors() {
driveMotor(true, 0, 0);
driveMotor(false, 0, 0);
}

# Arm animations

void performWaveAnimation() {
robotState = WAVING;

// Right arm performs the wave; left arm stays neutral. setArmAngleSafe(RIGHT_ARM_CH, 120);
delay(250);

for (int i = 0; i < 3; i++) { setArmAngleSafe(RIGHT_ARM_CH, 75); delay(180);
setArmAngleSafe(RIGHT_ARM_CH, 120); delay(180);
}

setArmAngleSafe(RIGHT_ARM_CH, ARM_HOME); robotState = IDLE;
}

void performArmsUpAnimation() { robotState = ARMS_UP;

setArmAngleSafe(LEFT_ARM_CH, ARM_UP); setArmAngleSafe(RIGHT_ARM_CH, ARM_UP); delay(500);

armsHome();
robotState = IDLE;
}

void armsDown() {
setArmAngleSafe(LEFT_ARM_CH, ARM_DOWN);
setArmAngleSafe(RIGHT_ARM_CH, ARM_DOWN);
}
Calibration note: if your physical horn orientation is mirrored, do not change the safety limits first. Reverse the mapping for that servo or adjust the horn installation, then re-check the 45°–135° mechanical envelope.

WALL-E AI Platform — Super Master Guide — REV2 | Engineering + Firmware Revision | Page 9

# REVISION 2 — 8. Firmware: Sensors + Safety

# Battery monitor

float readBatteryVoltage() {
// INA219 must be installed on the battery-side measurement path. return ina219.getBusVoltage_V();
}

float readBatteryPercent() {
float v = readBatteryVoltage();

// Simple Li-ion approximation; calibrate for the chosen cell/load. float pct = (v - 3.20f) / (4.20f - 3.20f) * 100.0f;
return constrain(pct, 0.0f, 100.0f);
}

# Obstacle safety

const uint16_t SAFE_DISTANCE_MM = 200;

bool obstacleTooClose() {
VL53L0X_RangingMeasurementData_t m;
lox.rangingTest(&m, false);

if (m.RangeStatus == 4) return false; // invalid reading return m.RangeMilliMeter < SAFE_DISTANCE_MM;
}

void safetyCheck() {
if (robotState == MOVING && obstacleTooClose()) { stopMotors();
robotState = AVOIDING;
}

float battery = readBatteryPercent();

if (battery < 10.0f) {
stopMotors();
robotState = ERROR_STATE;
}
}

# Command layer — AI does not touch hardware directly

enum CommandType {
CMD_NONE,
CMD_FORWARD,
CMD_BACKWARD,
CMD_LEFT,
CMD_RIGHT,
CMD_STOP,
CMD_WAVE,
CMD_ARMS_UP,
CMD_ARMS_HOME,
CMD_LOOK_LEFT,
CMD_LOOK_RIGHT
};

void executeCommand(CommandType cmd) { switch (cmd) {
case CMD_FORWARD:
robotState = MOVING;
driveMotor(true, 1, 2200); driveMotor(false, 1, 2200); break;

case CMD_STOP:
emergencyStop();
break;

case CMD_WAVE:
performWaveAnimation();
break;

case CMD_ARMS_UP:
performArmsUpAnimation();
break;

case CMD_ARMS_HOME:
armsHome();
break;

default:
break;
}
}
The same command functions are used by the web dashboard and by the AI intent layer. This keeps behavior consistent and makes safety checks centralized.

WALL-E AI Platform — Super Master Guide — REV2 | Engineering + Firmware Revision | Page 10

# REVISION 2 — 8. Firmware: Web Dashboard

#include <WebServer.h>

WebServer server(80);

void handleWave() {
performWaveAnimation();
server.send(200, "text/plain", "Waved"); }

void handleArmsUp() {
performArmsUpAnimation();
server.send(200, "text/plain", "Arms up"); }

void handleArmsHome() {
armsHome();
server.send(200, "text/plain", "Arms home"); }

void handleStop() {
emergencyStop();
server.send(200, "text/plain", "Stopped"); }

void setupWebServer() {
server.on("/wave", handleWave); server.on("/armsup", handleArmsUp); server.on("/armshome", handleArmsHome); server.on("/stop", handleStop); server.begin();
}

void serviceWebServer() {
server.handleClient();
}

# Dashboard controls

Button | Endpoint | Function
Wave (Arms) | /wave | performWaveAnimation()
Arms Up | /armsup | performArmsUpAnimation()
Arms Home | /armshome | armsHome()
STOP | /stop | emergencyStop()

# Non-blocking upgrade for final firmware

The examples above use short delays to make the behavior easy to understand. For the final integrated robot, replace long delay()-based animations with a timed state machine so the web server, ToF safety, battery monitoring, and audio remain responsive while an arm is moving.

# AI / voice integration boundary

Keep the OpenAI transport layer separate from hardware control. The AI returns a validated intent such as WAVE, MOVE_FORWARD, LOOK_LEFT, or STOP; the local firmware decides whether and how to execute it. Never hardcode a secret API key into a distributable firmware image.

# 9. 3D Printing / STL Guidance

Fi 4 STL blanks jahzin (men chat sabe2, mershabin bel-2ab3ad el-muṣaḥḥaḥa): head_box.stl (60×35×45mm), neck_platform.stl (29×20×3mm), trapezoidal_body.stl (qa3ide 63mm → foo2 29mm), base_tracks.stl (63×65×32mm).

Na2es: arm mount brackets w el-arm segments zetohon mesh mawjoudin bel-blanks el-jahzin. Lezim tzidon yadawiyyan (Seksyon 4.1 fiya el-spec: 2 fatḥat servo horn 3al janbein el-trapezoidal_body.stl, w dhira3 brass wire/PLA taqriban 3-3.5cm).

Hayde solid boxes be-l-2ab3ad el-khareji el-mazbouṭa bas — el-slicer (Cura/PrusaSlicer) howe yalli byedir el-shell thickness w el-infill. El-cutouts (shashet TFT, 3adaset camera, thoqoub speaker, fatḥet servo) lazim tzidon b-Tinkercad/Fusion360/Blender aw b-slicer's cut tool.

# Khatawat el-Ta3dil (Tinkercad — sahle lal-mubtedi2in)

## 1. tinkercad.com → hesab majjani → "Create new design" 2. Ḍbeṭ waḥdet el-qiyas 3ala centimeter 3. Este3mel "Shell" tool la-tfarrigh kel qeṭ3a (byewaffer madde w yekhaffef el-wazn) 4. Ḍif fat-ḥat/dawa2er lal-cutouts (shashe, camera, speaker, servo horn)

5. Export → STL, w eftaḥ b-Cura/PrusaSlicer: Infill 20-25% Gyroid, Layer height 0.12-0.16mm

Badil asra3: dawwer 3ala Thingiverse/Printables 3an "small WALL-E robot head pan tilt" aw "mini robot chassis servo" w 3addel el-qiyasat 3ala el-namouzej el-jahez badal ma tebda2 men el-ṣifr.

WALL-E AI Platform — Super Master Guide — REV2 | Engineering + Firmware Revision | Page 11

# REVISION 2 — 8. Firmware Integration Checklist

# Master .ino integration order

Order | Module | Pass condition
1 | I²C scan | 0x40 PCA9685, 0x41 INA219, 0x29 ToF detected
2 | PCA9685 | PWM frequency = 50 Hz; channels respond
3 | Arms | CH6/CH7 reach HOME safely without binding
4 | Head | CH0/CH1 center at 90° and move within mechanical limits
5 | Motors | DRV8833 responds to forward/reverse/stop
6 | ToF | Obstacle < SAFE_DISTANCE triggers motor stop
7 | INA219 | Battery-side voltage/current reading plausible
8 | Display | ST7789 initializes with correct pins/driver
9 | Audio | MAX98357A output works without brownout
10 | Dashboard | Wave / Arms Up / Arms Home / STOP work
11 | AI | Voice intent calls command layer only

# Final architecture

VOICE / WEB / LOCAL INPUT
v
COMMAND / INTENT
v
SAFETY + STATE MACHINE
+-----+------+------+
MOTORS | HEAD | ARMS
CH2-CH5 | CH0-1 | CH6-7
DRV8833 | PCA9685 | PCA9685
N20 TRACKS

Sensors -> updateSensors() -> state/safety
Battery -> INA219 -> safety/status
ToF -> obstacle check -> motor stop
Build rule: freeze the mechanical dimensions and pinout before printing final parts. Then validate one subsystem at a time. The first complete milestone is: Move + Look + Wave + Speak/Hear + Detect obstacle + Stop.

WALL-E AI Platform — Super Master Guide — REV2 | Engineering + Firmware Revision | Page 1

# REVISION 2 — 10. Final Checklist

# Mechanical

☐ Head / neck / body / track dimensions confirmed in CAD ☐ Neck width fixed after servo clearance check ☐ Arm brackets + arm links are separate CAD/STL parts ☐ SG90 horn centered at 90° before installation ☐ 45°–135° arm sweep verified manually ☐ ≥5 mm clearance from tracks/body/screen ☐ Arm moving mass kept light

# Electrical

## ☐ MT3608 adjusted to 5.0V before connection ☐ Common GND verified ☐ INA219 installed on the battery-side measurement path ☐ PCA9685 = 0x40 / INA219 = 0x41 / ToF = 0x29 ☐ 100–470 µF bulk capacitor near servo rail ☐ DRV8833 motor rail kept separate from logic/servo current path

# Firmware

☐ One master .ino with one setup() and one loop() ☐ CH6/CH7 arm functions integrated ☐ Servo limits centralized at 45°–135° ☐ Motor speed is parameterized ☐ Emergency stop implemented ☐ ToF obstacle stop implemented ☐ Battery low-voltage behavior implemented ☐ Dashboard Wave / Arms Up / Arms Home / STOP tested ☐ AI calls the command layer rather than raw PWM

# Release milestone

Do not add more features until the base robot passes: Move → Look → Wave → Speak/Hear → Detect obstacle → Stop.

This REV2 preserves the original component choices and dimensions while making the arm geometry, power routing, firmware integration, safety limits, and dashboard control explicit.

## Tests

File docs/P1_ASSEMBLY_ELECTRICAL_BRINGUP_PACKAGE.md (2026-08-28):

# P1 Assembly, Electrical Preparation, and First-Power Package

Every blank value, physical assignment and rating is `VERIFY_ON_ARRIVAL` unless linked
to received-part evidence. Autonomous free-driving is prohibited.

## Mechanical/module assembly order

1. Reconcile inventory IDs, labels, photos and datasheets; quarantine mismatches.
2. Measure parts and print fit/interface coupons before editing production geometry.
3. Dry-assemble lower chassis, torso, service covers, feet and passive supports.
4. Verify sharp-edge removal, insulation barriers, hard-stop load paths and access.
5. Prepare controller/power standoffs and removable trays without powered parts.
6. Prepare wiring corridors, grommets, clamps, moving loops and service loops.
7. Install protected power distribution with every downstream load disconnected.
8. Install STM32 safety controller, debug access and logic-only harness.
9. Install ESP32 multimedia controller, antenna/USB access and logic-only harness.
10. Install one sensor branch at a time; defer actuators, display/audio/camera loads.
11. Install one mechanically restrained actuator branch at a time after identity tests.
12. Install display/camera/audio and optional cosmetic loads after required safety
    paths are verified. Close covers only after inspection and thermal checks.

Service removal order is the reverse, with source disconnected first. Battery,
power-distribution, debug, safe-stop and controller access must not require removing a
loaded moving mechanism.

## Fastener/spacer/bracket matrix

| Location/module | Fastener/thread | Length/stack | Spacer/insert/bracket | Retention/torque | Evidence/status |
|---|---|---|---|---|---|
| Chassis/torso shells | TBD | TBD | TBD | TBD | `VERIFY_ON_ARRIVAL`; print coupon/load path |
| Rear service cover | TBD | TBD | captive/serviceable TBD | TBD | repeated-removal test |
| Battery cassette/door | TBD | TBD | insulated restraint TBD | TBD | impact/retention/service test |
| ESP32/STM32/power trays | TBD | TBD | insulated standoffs TBD | TBD | exact hole pattern/clearance |
| Head rails/carriage/pan/tilt | TBD | TBD | bearing/yoke/hard-stop TBD | TBD | alignment, obstruction, cycle test |
| Shoulder/elbow/arm shells | TBD | TBD | yokes/bearings/belt brackets TBD | TBD | load/thermal/backlash test |
| Wheel pods/caster/feet | TBD | TBD | lock/hard-stop brackets TBD | TBD | traction/braking/fold-load test |
| Sensor/optical windows | TBD | TBD | light seals/carriers TBD | TBD | FOV/crosstalk/retention test |
| Cable clamps/strain relief | TBD | TBD | grommet/clamp TBD | TBD | bend/flex/pull test |

## Removable modules and fault containment

- Removable: battery cassette, rear electronics tray/cover, controller trays, wheel
  pods, arm modules, head rear hatch/sensor carrier, gripper/tools and optical insert.
- Each module receives identity labels and keyed/polarized connectors where the final
  verified connector system supports them.
- Separate logic, protected safety/motion, multimedia/cosmetic and high-current
  actuator branches. A cosmetic/optional fault must not remove local safety.
- Protect harnesses from pinch/shear, moving joints, sharp edges, heat and speaker/
  motor interference. Provide service slack without uncontrolled loops.
- Branch protection, disconnect and current-limit values remain TBD pending measured
  loads. Fault injection occurs only with appropriate current limitation and isolation.

## Power-tree worksheet

```text
received battery/bench source
  -> primary disconnect/protection [type/value TBD]
  -> protected distribution
       -> STM32 safety logic rail [regulator/protection TBD]
       -> actuator/drive branches [individually gated/protected; values TBD]
       -> ESP32/multimedia logic rail [regulator/protection TBD]
       -> display/camera/audio/belly optional branches [individually bounded]
```

| Node/branch | Source/load | Nominal/min/max V | idle/inrush/peak A | protection/fuse | wire/connector | measured evidence |
|---|---|---|---|---|---|---|
| Bench source / pack input | TBD | TBD | TBD | TBD | TBD | blank until measured |
| STM32 safety logic | TBD | TBD | TBD | TBD | TBD | blank until measured |
| ESP32/multimedia logic | TBD | TBD | TBD | TBD | TBD | blank until measured |
| Left/right drive | TBD | TBD | TBD | TBD | TBD | blank until measured |
| Head/arm/tool branches | TBD | TBD | TBD | TBD | TBD | blank until measured |
| Display/camera/audio/belly | TBD | TBD | TBD | TBD | TBD | blank until measured |

Common-reference/ground strategy must be schematic-reviewed. Record return paths,
shield/drain treatment, chassis connection if any, logic/power separation, ground-loop
risks and measurement points. Never infer common-ground suitability from connector
fit alone.

## Interface, connector and wiring worksheet

| Link | Semantic owner | Interface class documented | Final pins/connector | Cable/topology/separation | Gate |
|---|---|---|---|---|---|
| ESP32–STM32 | both; STM32 safety authoritative | Classical CAN/TWAI direction | TBD | topology/termination/length TBD | Phase 2B2 waiting |
| STM32–cliff/bumper/power | STM32 | sensor/discrete classes | TBD | separate/protect from motor noise | verify one at a time |
| STM32–drive/arms/head/tools | STM32 | protected actuator/tool classes | TBD | high-current separation and branch disconnect | commission individually |
| ESP32–display/camera/audio/belly/head range | ESP32 | multimedia/sensor classes | TBD | RF/audio/optical and moving-loop constraints | verify exact modules |
| Debug/flash/service | respective controller | USB/debug class TBD | TBD | accessible with actuator power disabled | verify board docs |

Final pins, connectors, gauges, fuse/current-limit/regulator values, CAN parameters and
measured deadlines are not frozen by this worksheet.

## First-power and bench sequence

| Gate | Required action/evidence | Failure action |
|---|---|---|
| 1 Visual/mechanical | labels/photos, polarity marks, foreign objects, insulation, fasteners, restraints, clearances | remain unpowered; quarantine/rework |
| 2 Continuity/short | source rails to return, rail isolation, polarity, chassis/ground plan, branch disconnects | remain unpowered; locate fault |
| 3 Isolated source | current-limited bench source, verified range, operator disconnect, no battery/actuator loads | disconnect immediately on anomaly |
| 4 Rails/regulators | verify each unloaded rail then representative bounded load; record V/I/temperature | disable branch; redesign sizing/protection |
| 5 Controller-only | logic-only STM32 carrier identity/debug/reset/watchdog/safe outputs | remove power; no actuator connection |
| 6 ESP32 boot | exact board/USB/boot/recovery/logs with optional loads absent | remove optional load; preserve STM32 safety |
| 7 STM32 boot | commissioning firmware, debug, reset/watchdog and actuator gates disabled | unpowered recovery; no motion |
| 8 Communication | semantic session/liveness only; loss/reboot cannot arm motion | remain actuator-power-disabled |
| 9 Sensors | one sensor at a time: identity, plausible/stale/disconnect/stuck response | mark failed; no integrated gate |
| 10 Actuators | one restrained actuator: identity/model/voltage/bus/baud/ID/direction/zero/range/feedback/current/temperature | cut branch power; return to disabled |
| 11 Multimedia | display/audio/camera/range/belly individually, optional failure isolated | degrade optional branch only |
| 12 Safe fault injection | disconnect/reset/stuck/open and protected shorts only where instrumented | physical disconnect; inspect |
| 13 Safe-stop observation | trigger, command rejection, actual state/power feedback, measured timing blank until observed | no further motion; diagnose |
| 14 Integrated bench | required sensors + safety + bounded semantic commands while restrained | return to actuator-power-disabled |
| 15 Restrained motion | only after signed prior gates; reduced verified limits, one behavior at a time | immediate safe stop and rollback |

No autonomous free-driving occurs in P1 first bring-up. A received/accepted command is
not executed until actual state confirms it.

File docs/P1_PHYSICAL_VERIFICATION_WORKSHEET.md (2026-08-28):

# P1 Arrival-Day Physical Verification Worksheet

Do not prefill measured fields. Attach inventory ID, dated photo, instrument, method,
operator and source/datasheet to every result. A CAD estimate is not a measurement.

## Part identity and fit

| Check | Inventory ID | Documented value/source | Measured value | Photo/ref | Pass/fail/decision |
|---|---|---|---|---|---|
| Exact manufacturer/model/variant/revision/label/serial | | | | | |
| Board/body length x width x height | | | | | |
| Mounting-hole pattern, diameter and datum | | | | | |
| Connector type, cavity/pin count, location and orientation | | | | | |
| Cable/backshell exit and minimum observed bend radius | | | | | |
| Component/assembly mass | | | | | |
| CAD envelope/interference/service-removal fit | | | | | |

## Power, actuators and mobility

| Check | Inventory ID/test condition | Documented value | Measured value | Instrument/log | Result |
|---|---|---|---|---|---|
| Battery/cell/pack exact dimensions and mass | | | | | |
| Battery provenance/protection/connector/polarity | | | | | |
| Rail voltage unloaded/loaded/inrush | | | | | |
| Actuator exact identity/model/voltage class | | | | | |
| Bus/baud/ID/feedback discovery with motion disabled | | | | | |
| Actuator travel, zero, direction, hard/end state | | | | | |
| Motor/servo idle, no-load and bounded-load current | | | | | |
| Bounded-load temperature versus time/ambient | | | | | |
| Wheel diameter, width, runout and tread | | | | | |
| Wheel traction/braking/turn scrub by surface | | | | | |
| Caster height/friction and support contact | | | | | |

## Optics, sensors, audio and moving cables

| Check | Inventory ID/test condition | Documented value | Measured/observed value | Evidence | Result |
|---|---|---|---|---|---|
| Sensor/camera field of view and occlusion | | | | | |
| VL53L1X window transmission/crosstalk by material/air gap | | | | | |
| Camera lens/focus/FPC clearance through head range | | | | | |
| Display IC/interface/FPC/touch and active area | | | | | |
| Magnet pull vs material/air gap and temperature | | | | | |
| Speaker/microphone chamber/port/cable clearance | | | | | |
| Head/arm cable loop bend, pinch and full-range clearance | | | | | |
| Retraction/flex cycle count and observed cable wear | | | | | |
| Cliff sensing: white/matte black/glossy/metal/mirror/glass/cloth/edge/sunlight/dirt | | | | | |

## Mass and center-of-mass inputs

| Module/configuration | Mass measured | Datum | Balance/COM observation | Uncertainty/method | Evidence |
|---|---|---|---|---|---|
| Base/chassis | | | | | |
| Battery/pack | | | | | |
| Torso/electronics | | | | | |
| Head assembled | | | | | |
| Left/right arm assembled | | | | | |
| Tools/payloads | | | | | |
| Complete active/sleep/shutdown robot | | | | | |

After data entry, update the inventory row, Device Identity, Hardware Profile candidate,
CAD parameter provenance and risk/gate result together. Conflicts require Product Owner
review; never silently substitute a physically different part.

## Physical no-go sign-off

- [ ] Exact battery protection and safe source/protection path verified.
- [ ] Every powered actuator identity/voltage/direction/range/feedback verified.
- [ ] Current/thermal limits derived from measurements and reviewed.
- [ ] Cliff/bumper and required local safety responses physically pass.
- [ ] Moving cables/strain relief clear full constrained range.
- [ ] Range window/camera/display interfaces pass with received parts.
- [ ] Physical safe-stop delivery and actual-state confirmation observed.
- [ ] Restrained commissioning completed and signed.

If any box is blank or failed: no autonomous motion and no unrestrained driving.

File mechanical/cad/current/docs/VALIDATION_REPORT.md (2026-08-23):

# ZI-E CAD v0.3 — Automated Geometry / Engineering Validation

**Result:** 38/39 checks pass. Failed checks are design restrictions or freeze gates, not silently ignored.

Estimated mass: **2.45 kg**; active estimated COM: **(-0.6, -2.4, 91.3) mm**.

| Check | Value | Target | Result |
|---|---:|---|---|
| Head bay side clearance per side | 3.5 | >= 1.5 mm | PASS |
| Head bay depth clearance per side | 4.0 | >= 2.0 mm | PASS |
| Display side bezel each side | 15.740000000000002 | >= 10 mm | PASS |
| Display vertical margin total | 26.740000000000002 | >= 20 mm | PASS |
| Camera-to-lidar horizontal packaging gap | 2.25 | >= 2 mm | PASS |
| Lidar carrier inside head width | 17.25 | >= 10 mm side structure | PASS |
| Belly prototype PCB inside reserved keepout width | 28.700000000000003 | >= 20 mm spare | PASS |
| Belly prototype PCB inside reserved keepout height | 15.0 | >= 10 mm spare | PASS |
| Belly optical window thickness | 1.2 | 0.8-1.5 mm prototype range | PASS |
| Sleep visible active-screen fraction | 0.847 | >= 0.75 | PASS |
| Shutdown head top flush | 0.0 | <= 1 mm above body top | PASS |
| ACTIVE minimum Z | -0.0 | >= -0.1 mm | PASS |
| SLEEP minimum Z | -0.0 | >= -0.1 mm | PASS |
| SHUTDOWN minimum Z | -0.0 | >= -0.1 mm | PASS |
| Shutdown overall height | 182.0 | ~182 mm | PASS |
| Active overall height | 282.0 | <= 290 mm | PASS |
| Arm distal collision with torso: active | 0.0 | 0 mm^3 | PASS |
| Arm distal collision with torso: stow | 0.0 | 0 mm^3 | PASS |
| Arm distal collision with torso: reach | 0.0 | 0 mm^3 | PASS |
| Arm distal collision with torso: desk | 0.0 | 0 mm^3 | PASS |
| Active tire desk contact | 0.0 | ~0 mm | PASS |
| Wheel tire/base collision active | 1.072 | < 2 mm^3 numerical | PASS |
| Stowed wheel ground clearance | 5.96 | >= 4 mm | PASS |
| Wheel tire/base collision stowed | 0.0 | < 2 mm^3 numerical | PASS |
| Head shell/torso collision ACTIVE | 0.0 | 0 mm^3 | PASS |
| Head shell/torso collision SLEEP | 0.0 | 0 mm^3 | PASS |
| Head shell/torso collision SHUTDOWN | 0.0 | 0 mm^3 | PASS |
| Head lift nominal linear speed | 6.67 | ~6.7 mm/s | PASS |
| Head protected travel time | 15.0 | <= 18 s | PASS |
| Rated drive speed | 0.251 | 0.20-0.30 m/s | PASS |
| Head tilt rated torque margin | 2.7 | >= 2.0x | PASS |
| Wrist pitch rated torque margin | 1.98 | >= 1.7x | PASS |
| Shoulder rated torque sanity margin | 1.68 | >= 1.5x | PASS |
| Elbow rated torque sanity margin | 1.74 | >= 1.5x | PASS |
| Estimated total mass | 2448 | informational | PASS |
| Baseline static support margin | 20.4 | >= 18 mm | PASS |
| One-arm 250g forward static margin | 19.8 | >= 15 mm | PASS |
| Two-arm 2x250g forward static margin | 12.1 | >= 15 mm for normal driving | RESTRICT / VERIFY |
| Protected worst commanded rail budget | 15.5 | < 20 A cell ceiling | PASS |

## Important interpretation

- The two-arm 2×250 g forward case is intentionally allowed to fail the normal-driving margin. Firmware must treat that combination as a restricted manipulation state (base stationary or much lower payload/acceleration).
- Torque calculations use **rated torque**, never stall torque, and include a simple belt-loss factor. Physical thermal/load tests remain the authority.
- Mass values tagged low/medium confidence must be replaced with measured values after parts are printed/bought.
- Collision tests cover the defined key poses. Continuous trajectory collision checking belongs in the simulation/firmware phase.

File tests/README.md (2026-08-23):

# Tests

Tests will be added for firmware safety, communication protocol, robot-state behavior, simulations, and later hardware bring-up.

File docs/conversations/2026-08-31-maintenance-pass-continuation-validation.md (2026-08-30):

# 2026-08-31 — Maintenance pass continuation and validation

The maintenance/hardening pass continued from the existing uncommitted tree at
`3243dd78cf5425eb92c0a88cc5dd4b4f58d4bbbe` on branch
`refactor/modular-hardware-architecture`; no reset, checkout, commit, push, flash, or
powered hardware action occurred.

Adversarial review found that the separately bench-tested HW678/S3-N16R8 board had
been assigned to inventory ID HW-001 without an explicit repository link proving the
physical identity. The evidence overlay now names it `SPARE-HW678`; HW-001 remains an
inventory spare awaiting a reviewed photo/order-to-unit link. HW-002 remains ordered,
NOT_ARRIVED, UNVERIFIED, and unflashed. The evidence parser now validates every
hardware item's exact conservative state tuple and fails closed on any promotion.

Additional repairs made the Git safe-directory argument cross-platform, expanded CSV
formula neutralization for whitespace/control prefixes without coercing non-strings,
escaped remaining dynamic HUD values, and invalidated visible readiness evidence on
authentication/request failure. Archive review found that a broad `* -text` rule
would have converted moved checkout line endings into rewritten Git blobs; the rule
was narrowed so all 65 historical move pairs retain their original prospective blobs.

Validation used repository-local pytest temporary storage. The final App suite and
fallback counts, host configure/build/CTest result, frontend/PowerShell parsing,
relative-link audit, secret/truth/artifact scans, and performance measurement are
reported in the Product Owner handoff for this session. The sandbox still cannot
launch EIM (`Access is denied`), so the previous official ESP-IDF v6.0.2 generic
cross-build remains the host-verified result; flash and first integrated power remain
NOT_AUTHORIZED, commissioning remains NOT_STARTED, and Phase2B2 remains
WAITING_FOR_VERIFIED_INPUTS.

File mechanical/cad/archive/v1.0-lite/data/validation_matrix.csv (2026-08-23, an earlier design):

test | value | limit_or_target | pass | notes
Head bay side clearance per side | 3.5 | >= 1.5 mm | True | Docking only at centered pan/defined tilt.
Head bay depth clearance per side | 4.0 | >= 2.0 mm | True | Allows shell tolerance and cable-safe docking.
Display side bezel each side | 15.740000000000002 | >= 10 mm | True | Provides structure around glass and room for tilt frame.
Display vertical margin total | 26.740000000000002 | >= 20 mm | True | Shared with top camera/mic brow.
Sleep visible active-screen fraction | 0.847 | >= 0.75 | True | Neck hidden while most of face remains visible.
Shutdown head top flush | 0.0 | <= 1 mm above body top | True | Protected shutdown has no screen/camera exposure above top plane.
ACTIVE minimum Z | -0.0 | >= -0.1 mm | True | No geometry should penetrate the desk plane.
SLEEP minimum Z | -0.0 | >= -0.1 mm | True | No geometry should penetrate the desk plane.
SHUTDOWN minimum Z | -0.0 | >= -0.1 mm | True | No geometry should penetrate the desk plane.
Shutdown overall height | 182.0 | ~182 mm | True | Compact pod target.
Active overall height | 282.0 | <= 290 mm | True | Desktop scale.
Arm distal collision with torso: active | 0.0 | 0 mm^3 | True | Shoulder mount overlap intentionally excluded.
Arm distal collision with torso: stow | 0.0 | 0 mm^3 | True | Shoulder mount overlap intentionally excluded.
Arm distal collision with torso: reach | 0.0 | 0 mm^3 | True | Shoulder mount overlap intentionally excluded.
Arm distal collision with torso: desk | 0.0 | 0 mm^3 | True | Shoulder mount overlap intentionally excluded.
Active tire desk contact | 0.0 | ~0 mm | True | Powered wheels define two primary contact points.
Wheel tire/base collision active | 1.072 | < 2 mm^3 numerical | True | Near-zero boolean sliver is acceptable; no structural collision.
Stowed wheel ground clearance | 5.96 | >= 4 mm | True | Robot rests on four shutdown feet, not folded wheels.
Wheel tire/base collision stowed | 0.0 | < 2 mm^3 numerical | True | Near-zero boolean sliver is acceptable; no structural collision.
Head shell/torso collision ACTIVE | 0.0 | 0 mm^3 | True | Head bay clears the cosmetic shell at docking pan/tilt.
Head shell/torso collision SLEEP | 0.0 | 0 mm^3 | True | Head bay clears the cosmetic shell at docking pan/tilt.
Head shell/torso collision SHUTDOWN | 0.0 | 0 mm^3 | True | Head bay clears the cosmetic shell at docking pan/tilt.
Head lift nominal linear speed | 6.67 | ~6.7 mm/s | True | T5x2 at 200 RPM; full protected travel ~15 s.
Head protected travel time | 15.0 | <= 18 s | True | Can switch to faster N20 if user testing wants faster motion.
Rated drive speed | 0.251 | 0.20-0.30 m/s | True | Software speed is lower near edges and during manipulation.
Head tilt rated torque margin | 2.7 | >= 2.0x | True | Assumes head COM within 20 mm of tilt axis; measure real head before freeze.
Wrist pitch rated torque margin | 1.98 | >= 1.7x | True | 150 g tool at 40 mm; heavier tools trigger ST3036/HL2915 backup.
Shoulder rated torque sanity margin | 1.68 | >= 1.5x | True | Approximation only; dummy-arm thermal/load test remains mandatory.
Elbow rated torque sanity margin | 1.74 | >= 1.5x | True | Approximation only; uses planned ~2:1 belt reduction.
Estimated total mass | 2422 | informational | True | Current estimate before measured printed/component mass.
Baseline static support margin | 19.8 | >= 18 mm | True | Minimum distance of COM projection to primary support triangle edge.
One-arm 250g forward static margin | 20.0 | >= 15 mm | True | Allowed only at reduced base speed/acceleration.
Two-arm 2x250g forward static margin | 12.2 | >= 15 mm for normal driving | False | Expected restricted case: base lock/very-low acceleration or smaller payload.
Protected worst commanded rail budget | 15.5 | < 20 A cell ceiling | True | Independent eFuses/current limits prevent theoretical all-joint stall from reaching cell ceiling.

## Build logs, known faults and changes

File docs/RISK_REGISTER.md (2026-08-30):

# ZI-E Risk Register

## Package/update policy foundation risks — 2026-08-28

- Digest, signer, and verification values are abstractions, not production crypto.
- Atomicity is in-memory only; durable crash consistency needs a later threat model.
- Compatibility defaults keep policy wiring optional for old fixtures; production
  composition must wire PackagePolicy into ExtensionHost and HostRuntime.

This register tracks credible problems requiring prevention, detection, recovery, and
verification. It does not approve implementation or freeze unresolved hardware values.

| ID | Risk | Subsystem | Likelihood | Impact | Prevention | Detection | Recovery | Test strategy | Current status | Evidence/source |
|---|---|---|---|---|---|---|---|---|---|---|
| R-PROTO-001 | A stale or rebooted controller regains motion authority | ESP32–STM32 protocol | Medium | Critical | Hello creates a candidate only; require a fresh valid heartbeat; bind authority to configured controller and boot session; reject the immediately retired session; authenticated/persistent replay defense in later wire stage | Session mismatch/restart fault and audit log | Local safe stop, clear authority, renegotiate and recommission when required | Reboot/replay/fuzz/fault-injection tests | OPEN: Phase 2B1 blocks Hello-only authority and immediate retired-session replay; long-lived authenticated replay protection remains unimplemented for Phase 2B2 | OpenCyphal specification; micro-ROS reconnect issues #572, #912, #1809 |
| R-PROTO-002 | Duplicate/stale traffic masks a dead controller link | ESP32–STM32 protocol | Medium | Critical | Only newer valid heartbeat sequences refresh a verified monotonic deadline | Local link-expiry fault independent of command receipt | STM32 local safe stop; explicit reconnect | Duplicate, reorder, wraparound, delay, loss, and event-loop stall tests | MITIGATING: host contract scaffolded; hardware path unverified | PX4 issue #16944; OpenCyphal specification |
| R-PROTO-003 | Forged or corrupted frames trigger false restart/fault or unsafe authority | ESP32–STM32 protocol/security | Medium | Critical | Hello never grants authority; reject stray/incompatible Hellos without mutating a healthy session; select integrity/authentication after threat and bus analysis; never expose raw actuator frames | Rejection counters, unexpected-peer/session diagnostics, restart faults for configured-peer boot changes | Fail closed on established-session expiry/restart, rate-limit renegotiation, service diagnostics | Corruption, spoofing, stray-Hello, configured-peer spoof, bus-flood, and denial-of-service fault injection | OPEN: Phase 2B1 limits trivial Hello takeover/teardown; no wire authentication or integrity mechanism selected | Secure-boundary requirement; independent Phase 2B1 review |
| R-SAFE-001 | Healthy transport heartbeat masks a stalled safety task | STM32 safety supervision | Medium | Critical | Independent critical-task supervision plus hardware watchdog fallback | Per-task liveness channels and watchdog reset cause | Local safe state and controlled reboot | Stall each critical task while communications remain healthy | OPEN: Phase 2C design/bench work | Zephyr task watchdog documentation |
| R-PROTO-004 | CAN priority, bursts, or retries exceed a safety-message deadline | ESP32–STM32 protocol | Medium | Critical | Complete message inventory; conservative stuffing bounds; priority-aware response-time analysis; bounded diagnostics | Deadline misses, queue high-water marks, arbitration/error counters | Drop/defer noncritical traffic; STM32 local safe state | Simultaneous release, diagnostic burst, arbitration, ACK/bit-error injection | OPEN: rates, priorities, bitrate, and deadlines unverified | `PHASE2B2_BUS_TIMING_ANALYSIS.md`; Bosch CAN 2.0; Espressif TWAI docs |
| R-PROTO-005 | Multi-frame semantic message is partially executed, confused across sessions, or exhausts reassembly memory | ESP32–STM32 protocol | Medium | Critical | Bounded transaction identity/reassembly; complete-before-dispatch; session binding; strict size/time limits | Fragment gap/order/duplicate/timeout counters | Discard whole incomplete message; never partially command motion | Loss/reorder/duplicate/reboot/stale-session/memory-pressure corpus | OPEN: fragmentation design intentionally not frozen | 8-byte Classical CAN limit; current 12-byte semantic identities |
| R-EXT-001 | Extension self-asserts trust, uses malformed enum values to bypass class rules, or receives declared permissions as automatic grants | Plugins/security | Medium | Critical | External registry assignment binds package/trust/controller/profile; exhaustive enum checks; typed permission requests; deny-by-default enforcement before execution | Registration/context mismatch, validation issue, permission audit, runtime authorization denial | Reject/quarantine/disable extension; synchronously revoke capability exposure | Self-claimed built-in, package/profile impersonation, protected-controller claim, out-of-domain enum, permission escalation, and confused-deputy tests | MITIGATING: in-memory registry rejects identity/trust/ownership escalation and revokes capabilities; runtime enforcement still OPEN | Independent adversarial review; VS Code Workspace Trust/runtime security; Zi-E safety boundary |
| R-EXT-002 | Declared capability becomes commandable without validation, health checks, or commissioning | Hardware/plugins | Medium | Critical | Separate declared/validated/active sets; explicit lifecycle; only active/degraded records resolve; ambiguous providers rejected | Registry invariant checks and identity-bound capability resolution | Clear active capability synchronously; fail/degrade/quarantine/disable/remove extension | Activation-before-validation, unvalidated active set, ambiguity, lifecycle, and synchronous revocation tests | MITIGATING: in-memory activation/resolution contract implemented; loader, runtime authorization, and commissioning binding remain OPEN | ros2_control inactive hardware lessons; ROS 2 lifecycle failures; Zi-E commissioning rule |
| R-EXT-003 | Executable content is smuggled into a cosmetic asset pack | Assets/plugins/security | Medium | High | Data-only asset class; no entrypoint or permissions; later archive allowlist and parser limits | Package/schema scan and integrity validation | Reject/quarantine package; protected system fallback | Entrypoint/script/archive traversal/polyglot corpus | MITIGATING: manifest contract rejects entrypoint/permissions; file inspection still OPEN | VS Code distinction between code entrypoints and data contributions |
| R-EXT-004 | Failed, stale, or impersonated configuration partially replaces active settings or escalates extension authority | Plugins/configuration/security | Medium | Critical | Authoritative package/device/profile binding; staged validation; monotonic revision; atomic snapshot replacement; forbidden authority/raw-control namespaces; lifecycle commit gate | Configuration result, revision/generation audit, binding mismatch, lifecycle check | Preserve active snapshot and discard staged/validated candidate | Invalid rollback, stale revision, impersonation, disabled/quarantined/removed commit, authority escalation, unknown-domain tests | MITIGATING: in-memory transaction contract implemented; persistence crash recovery and real hardware application rollback remain OPEN | ROS 2 atomic parameters; Kubernetes resourceVersion conflict semantics; Home Assistant migration failure states |
| R-API-001 | Plugin bypasses semantic authorization, resets replay ordering, impersonates another device, mutates state through events, or requests protected/raw control | Robot API/plugins/security | Medium | Critical | Core-bound command sessions with retired-ID rejection; typed command variants; fixed capability mapping; active registry package/device binding; sequence checks; separate event/state authority; no raw/protected plugin vocabulary | Command/session rejection result, source/capability audit, generation rejection | Reject intent without dispatch; preserve state; quarantine/disable through registry | Bound/replaced/retired/mismatched sessions, stale sequence, lifecycle/capability denial, impersonation, raw/unknown request, protected safety attempt, event isolation, stale-state tests | MITIGATING: in-memory session and authorization contracts implemented; authentication, persistence, dispatcher, runtime isolation, and physical enforcement remain OPEN | ROS 2 action goal/status separation; ROS 2 lifecycle active publishing; Home Assistant state-event failure reports |
| R-API-002 | Slow, failing, or ineligible event subscriber causes unbounded growth, blocks peers, or receives events after revocation | Robot API/event distribution | Medium | High | Fixed per-subscriber depth; deterministic drop-newest policy; typed overflow/failure results; lifecycle/capability recheck at publish and delivery; callback exception containment | Queue depth, overflow and subscriber-failed results | Drop newest for affected full queue; clear ineligible queue; unsubscribe/quarantine faulty subscriber | Duplicate subscription, overflow, exception isolation, quarantine/disable delivery denial, unknown-domain tests | MITIGATING: synchronous in-memory contract implemented; thread/scheduler/process isolation and operational telemetry remain OPEN | ROS 2 QoS keep-last depth; rclcpp issue #2196 |
| R-RUNTIME-001 | A checkpoint or partial restart is mistaken for live authority and revives stale motion, extension, device, provider, or presentation state | Host runtime/recovery | Medium | Critical | Checkpoint copied semantic intent only; exact schema/bounds; exclude sessions/handles/leases/setpoints/heartbeat/sequence authority; fail-safe stopped preparation; exact prior-device comparison; explicit subsystem reauthorization; bounded attempts | Typed checkpoint/version/device mismatch and readiness reason; runtime generation and fresh SDK epochs | Remain failed/non-moving; correct authoritative state; explicitly prepare and complete recovery | Corrupt/unknown checkpoint, replacement-device rejection, stopped recovery, stale-handle, fresh-epoch, and retry-limit tests | MITIGATING: in-memory contract implemented; persistent serialization integrity, crash consistency, authentication, and physical safe stop remain OPEN | ros2_control lifecycle/restart guidance; issues #2508 and #2079; Zi-E stale-session rules |
| R-PROVIDER-001 | A temporary provider failure creates permanent fallback lock-in, cross-modality substitution, or capability widening | Host providers | Medium | High | Separate exact LLM/STT/TTS/Wake policies; host-owned monotonic priority; bounded attempts; registry reauthorization per attempt; provider cannot mutate priority | Typed diagnostic chain, policy generation, exact selected package | Retry current configured primary on later invocation only when authorized/healthy; otherwise bounded fallback/exhaustion | Temporary primary recovery, stale policy generation, unknown modality, authorization lost during fallback, exact-capability mismatch | MITIGATING: deterministic in-memory policy implemented; real health/network/credentials remain excluded | Home Assistant core issues #174990 and #157017; provider foundation tests |
| R-COMMISSION-001 | Simulation/software readiness is mistaken for physical verification and enables unsafe prototype motion | Prototype commissioning | Medium | Critical | Separate typed/documented physical progression; operator evidence; logic-only first power; one bounded actuator at a time; autonomous motion prohibited | Signed/dated arrival, measurement, sensor, actuator, and safe-stop worksheets | Remove actuator authority; return to actuator-power-disabled or unpowered state | Gate-failure drills, identity/direction/range/feedback checks, physical safe-stop test | OPEN: P1 process ready; all physical evidence `VERIFY_ON_ARRIVAL` | ZI-E safe commissioning rule; Reachy/LeRobot failure harvest |
| R-P1-001 | Stale BOM/CAD candidate is mistaken for the purchased variant | Inventory/CAD | High | High | Canonical reconciliation; exact inventory ID/variant/photo/source; archived CAD non-authoritative; no silent substitution | Sheet conflict report, label/photo/dimension mismatch, duplicate identity check | Quarantine item; mark UNDECIDED/REPLACE; Product Owner review; update CAD/profile together | Intake dry run with mismatched suffix/revision and conflicting dimensions | OPEN: schema/package ready; purchased inventory not yet supplied | `HARDWARE_SOURCE_OF_TRUTH_RECONCILIATION.md`; intake schema |
| R-P1-002 | CAD model estimates are treated as measured fit, mass, torque, current, thermal or stability evidence | Mechanical/electrical | High | Critical | Label all v0.3 numeric outputs as model parameters/estimates; received-part coupons/measurements and physical gates | Provenance audit; blank measured fields; model-vs-measured comparison | Return affected geometry/limits to parametric; re-run CAD/bench checks | Deliberate CAD/received mismatch and missing-measurement no-go review | OPEN: CAD internally validated; physical evidence absent | `P1_CAD_FREEZE_CANDIDATE.md`; CAD validation report |
| R-P1-003 | First power energizes a short, wrong-polarity rail, unverified battery/protection path or multiple actuator branches | Power/commissioning | Medium | Critical | Unpowered inspection/continuity; isolated current-limited source; loads disconnected; rail-by-rail then one actuator at a time; operator disconnect | Meter/current-limit/thermal observation and signed gate sheet | Immediate disconnect; remain unpowered; quarantine/rework branch | Wrong-polarity/open/short drill only with safe instrumentation; first-power checklist audit | OPEN: process ready; exact protection/ratings TBD | `P1_ASSEMBLY_ELECTRICAL_BRINGUP_PACKAGE.md` |
| R-P1-004 | Cable/connector routing causes pinch, flex failure, noise coupling, short or unsafe service sequence | Harness/mechanical | Medium | Critical | Measured bend radius, strain relief, edge protection, service loops, branch separation, removable trays, power-first disconnect | Full-range visual inspection, pull/flex cycles, continuity/noise/temperature observation | Remove power; replace/reroute harness; return motion gate to disabled | Head/arm retraction cycle, service-removal and injected open-circuit tests | OPEN: routes conceptual; received harness/connectors TBD | P1 CAD/assembly/physical worksheets |
| R-P1-005 | Unverified cliff/traction/range-window behavior permits edge fall, collision or false confidence | Sensors/mobility | Medium | Critical | STM32-owned cliff/bumper safety; surface/FOV/window/crosstalk matrix; restrained traction/braking; range sensor remains non-safety | Raw/plausible/fault response logs and physical surface matrix | Disable motion; adjust geometry/sensors; add mechanical mitigation if required | White/black/glossy/metal/mirror/glass/cloth/sunlight/dirt plus traction/braking tests | OPEN: all physical behavior `VERIFY_ON_ARRIVAL` | Freeze gates; physical verification worksheet |
| R-P1-006 | Hardware mapping exposes raw control or assigns protected safety to ESP32/App/plugin | Hardware/software integration | Low | Critical | Canonical ownership map; STM32 built-in protected modules; semantic capabilities only; registry/profile exact identity | Architecture/profile review and raw-namespace tests | Reject mapping/profile/extension; remove authority | Wrong-owner/raw-capability/adversarial mapping review | MITIGATING: software boundary frozen; production drivers not started | Hardware reconciliation; Software Architecture Freeze |
| R-ESP-001 | Camera or touch component/IDF mismatch aborts the ESP32 presence runtime | ESP32 presence | Medium | High | Verified per-board binding; locked IDF/component matrix; optional capability isolation | No-flash build matrix, typed init faults, boot without camera/touch tests | Disable failed optional capability; retain face/network/audio where safe | Wrong sensor, missing touch, pixel-format/allocation failure, repeated init | OPEN: HW-002 ordered/unverified; target disabled | XiaoZhi issues #1646/#1684; pinned donor audit |
| R-AUDIO-001 | Audio concurrency or weak-network recovery strands listening/playback or consumes unbounded buffers | ESP32 audio/transport | Medium | High | Bounded queues/frames; session/generation binding; cancellation and deterministic disconnect transition | Queue high-water, session state, typed disconnect/codec faults | Drop stale audio, close session, return to bounded local presence state | Second utterance, reconnect, simultaneous capture/playback, malformed packet corpus | OPEN: audio hardware and runtime absent | XiaoZhi issues #1684/#892; pinned donor audit |
| R-FACE-001 | Untrusted or oversized Face Pack executes content or exhausts flash/PSRAM | Presence/assets | Medium | High | Data-only abstract handles; bounded manifest; hash/license/provenance; no entrypoint/URL execution; verified storage budget | Pack validation and storage accounting before activation | Reject/quarantine pack; use verified core fallback | Traversal/script/URL, duplicate ID, oversize, bad hash, incompatible engine tests | MITIGATING: host validator implemented; archive parser/storage enforcement deferred | `FACE_ENGINE_INTERFACE_V1.md`; adversarial review |
| R-TRANSPORT-001 | Unbounded or stale Host/ESP32 control input exhausts memory or revives authority | Presence transport | Medium | Critical | 16 KiB cap, exact envelope, version/type allowlist, bounded nesting and active session/generation | Typed rejection diagnostics | Drop input and require fresh session | Invalid JSON/version/type, stale identity, path and size corpus | MITIGATING: decoder implemented; authenticated wire transport deferred | Host/ESP32 V1 and protocol tests |
| R-MEDIA-001 | Audio/image buffering grows without bound or crosses sessions | ESP32 media | Medium | High | Fixed queues/frames, drop-newest, reset-on-session and 2 MiB image ceiling | Drop/underflow/oversize diagnostics | Clear queue and reject capture | Overflow, underflow, reset and oversize tests | MITIGATING: host model; embedded allocation deferred | Donor audit and media tests |

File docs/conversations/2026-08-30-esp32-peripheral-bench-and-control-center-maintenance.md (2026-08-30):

# 2026-08-30 — ESP32 peripheral bench evidence and maintenance

Superseding note: HW-008's unpowered state below was accurate for this session but was
superseded by the independent functional bench evidence in
[the 2026-08-31 final bench delta](2026-08-31-final-bench-evidence-delta.md).

Purpose: preserve durable Product Owner evidence and the repository-maintenance
outcome without treating chat as hardware authority.

## Physical corrections and evidence

- HW-002, the intended final camera/Presence board, has **not arrived**. It remains
  ordered and unverified. No actual revision, memory, sensor, pinout, USB topology, or
  power behavior is known.
- The present board is a separate spare: PCB HW678 V0.0.0, module marking Sixspan
  S3-N16R8. Read-only identity reported ESP32-S3 QFN56 rev v0.2, dual core + LP,
  Wi-Fi/Bluetooth 5 LE, 40 MHz crystal, 16 MB quad/3.3 V flash, and 8 MB embedded OPI
  PSRAM. Serial bench firmware, PSRAM, onboard GPIO48 RGB colors/off, GPIO0 BOOT
  input, and reset recovery passed. These observations do not define HW-002.
- The HW678 3V3 rail measured 3.35 V. Its silkscreen pin marked 5Vin measured only
  approximately 0.28–0.30 V in both tested USB power modes and is not a verified 5 V
  output.
- HW-006 MAX9814 passed an independent functional bench on the spare board: power,
  analog bias, ESP32 ADC capture, acoustic response, and gain wiring all responded.
  Bias was approximately 1215–1219 mV; example sound windows were approximately
  393–767 mV peak-to-peak. GAIN-to-3V3 selected the approximately 40 dB mode; AR was
  unconnected. GPIO4 was temporary bench wiring only. Production pin, placement,
  quality calibration, and integrated audio commissioning remain open.
- HW-007 carrier marking is VL53L0/1X V2. Probe address 0x29 and register 0xC0 = 0xEE
  verify VL53L0X silicon identity. Ranging was unstable and included invalid/zero/
  65535-like results; electrical/solder continuity is suspect. The unit is quarantined
  pending rework or replacement, not declared destroyed, and must not be powered in
  this pass. GPIO5/GPIO6 were temporary bench I2C pins only.
- HW-008 WS2812-family breakout is present but unpowered. Functional testing is
  blocked until a verified suitable 5 V source exists; HW678 5Vin must not be used.
- HW-010 remains DO_NOT_POWER_OR_CONNECT.
- HW-017 multimeter is physically present and in active bench use. No unverified
  safety-category claim is promoted.

Temporary GPIO4/5/6/48 observations are evidence records, not production assignments.
No powered hardware action occurred during the repository maintenance pass.

## Software/toolchain evidence retained

- Official ESP-IDF v6.0.2 generic ESP32-S3 configure/compile/link/image/size passed
  from the canonical Windows repository path containing spaces.
- Profile remains GENERIC_UNVERIFIED_ESP32S3 with physical bindings disabled.
- Flash remains NOT_AUTHORIZED and no COM port is selected by the fixed workflow.
- The 2 MB IDF flash-image setting is build configuration only, not HW-002 evidence.

## Maintenance outcomes

- Control Center 0.05 derives software and bench readiness from a bounded,
  schema-validated repository evidence record and fails closed if it is malformed.
- Repository metadata uses a short cache; safety/runtime state is not cached.
- HUD refresh has one request owner with generation/abort guards, hidden-tab
  suppression, bounded event rows, and no persisted browser token.
- CSV exports neutralize spreadsheet formula-leading cells.
- The root README and concise Current State now distinguish software readiness from
  physical readiness.
- Historical bundles, exports, migration manifests, and the former chronological
  Current State were preserved in clearly labeled archive areas.

## Unchanged safety gates

STM32 remains final physical motion/safety authority. First integrated power is not
authorized, physical commissioning is not started, and Phase2B2 remains
WAITING_FOR_VERIFIED_INPUTS.

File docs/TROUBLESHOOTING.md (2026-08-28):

# Troubleshooting

For HTTP 401, use the `.env` bearer token without logging it. For chat 503, configure
`ZIE_HERMES_COMMAND=hermes`, confirm Hermes 0.20.6, and authenticate it separately.
Keep the session name stable.

For voice 503, configure ElevenLabs or the Zi-Nanami fallback. Stop affects remaining
chunks, not buffered audio. If startup reports an ownership file, follow recovery
instead of killing arbitrary PIDs. The pytest configuration uses writable runtime
cache paths and treats unexpected warnings as failures.

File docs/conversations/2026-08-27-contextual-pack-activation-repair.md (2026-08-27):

# 2026-08-27 — Contextual pack activation repair

## Request

Resume from `a5ef482` and make one narrow correction: stop representing contextual
face/sound pack activation with one global `PackState::active`. Support selection in
multiple contexts, isolate replacement, invalidate all affected selections after
registry revocation, make missing-context reads non-creating, preserve validation
state, and require explicit activation after lifecycle recovery. Keep Phase 2B2
`WAITING_FOR_VERIFIED_INPUTS` and add no adjacent architecture or hardware work.

## Outcome

- Pack records now retain only declared/validated data state; context records are the
  sole activation truth.
- Activation creates contexts explicitly, while active-pack queries only search
  existing contexts and fail closed when absent.
- Use-time lifecycle/capability failure clears the revoked pack from every existing
  context, without disturbing other packs or contexts.
- Focused tests cover shared face/sound selection, isolated replacement, all-context
  revocation, read-only missing lookup, preserved validation, and explicit recovery
  activation.
- Phase 2B2 remains `WAITING_FOR_VERIFIED_INPUTS`; no CAN/framing work was added.

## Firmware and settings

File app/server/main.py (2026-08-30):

from __future__ import annotations

import asyncio
from contextlib import asynccontextmanager
from pathlib import Path

from fastapi import Depends, FastAPI, Header, HTTPException, Request, WebSocket, WebSocketDisconnect, status
from fastapi.responses import FileResponse, Response, StreamingResponse
from fastapi.staticfiles import StaticFiles
from pydantic import BaseModel, ConfigDict, Field

from app.inventory.store import InventoryStore
from app.inventory.reconciliation import build_reports

from app.robot.state_machine import RobotController, RobotState
from app.runtime.adapter import (
    HostRuntimeAdapter,
    RequestPhase,
    SemanticCommandRequest,
    SimulatorRuntimeAdapter,
    TargetMode,
    UnavailableRuntimeAdapter,
)
from app.providers.policy import app_provider_status
from app.integrations.hermes import HermesBridge, route_message
from app.security.audit import AuditLog
from app.security.auth import BearerAuth
from app.server.config import Settings, load_settings
from app.server.control_center import (
    ACTUATORS,
    WorkspacePreview,
    cockpit_status,
    developer_actions,
    inventory_preview,
    inventory_schema,
    repository_status,
    run_developer_action,
    REPOSITORY_ROOT,
)
from app.version import APP_VERSION
from app.server.events import EventBus
from app.server.metrics import system_metrics
from app.server.state import StateCore
from app.voice.providers import command_synthesizer, elevenlabs_synthesizer
from app.voice.service import VoiceService
from app.voice.stt import LocalTranscriber


class RobotCommandRequest(BaseModel):
    target: RobotState
    timeout: float = Field(gt=0, le=30)


class MuteRequest(BaseModel):
    muted: bool


class ChatRequest(BaseModel):
    message: str = Field(min_length=1, max_length=16000)


class SpeakRequest(BaseModel):
    text: str = Field(min_length=1, max_length=10000)


class DeveloperActionRequest(BaseModel):
    model_config = ConfigDict(extra="forbid")
    action_id: str = Field(min_length=1, max_length=40, pattern=r"^[a-z_]+$")


class PresentationPreviewRequest(BaseModel):
    model_config = ConfigDict(extra="forbid")
    expression: str = Field(pattern=r"^(neutral|happy|curious|sleepy|warning)$")
    face_pack: str = Field(default="builtin-preview", pattern=r"^[a-z0-9_-]{1,40}$")
    brightness: int = Field(ge=0, le=100)
    animation_speed: int = Field(ge=0, le=100)
    rgb_brightness: int = Field(ge=0, le=100)
    rgb_pattern: str = Field(pattern=r"^[a-z0-9_-]{1,40}$")
    display_test_pattern: bool = False


class ActuatorPreviewRequest(BaseModel):
    model_config = ConfigDict(extra="forbid")
    slot: str
    operation: str = Field(pattern=r"^(enable|jog_plus|jog_minus|stop)$")
    speed: int = Field(ge=1, le=25)


class DrivePreviewRequest(BaseModel):
    model_config = ConfigDict(extra="forbid")
    direction: str = Field(pattern=r"^(forward|backward|left|right|stop)$")
    speed_limit: int = Field(ge=0, le=40)
    deadman: bool


class InventoryCreateRequest(BaseModel):
    model_config = ConfigDict(extra="forbid")
    expected_revision: int = Field(ge=0)
    inventory_id: str = Field(min_length=1, max_length=64, pattern=r"^[A-Za-z0-9][A-Za-z0-9._-]*$")
    part_name: str = Field(min_length=1, max_length=200)
    manufacturer: str = Field(default="", max_length=200)
    model_exact_variant: str = Field(default="", max_length=200)
    quantity: int = Field(ge=1, le=10000)
    physical_status: str = Field(pattern=r"^(RECEIVED|ORDERED|NOT_BOUGHT|UNKNOWN)$")
    purchase_link_reference: str = Field(default="", max_length=1000)
    photo_reference: str = Field(default="", max_length=1000)
    storage_location: str = Field(default="", max_length=200)
    notes: str = Field(default="", max_length=1000)


class InventoryEditRequest(BaseModel):
    model_config = ConfigDict(extra="forbid")
    expected_revision: int = Field(ge=0)
    part_name: str | None = Field(default=None, min_length=1, max_length=200)
    manufacturer: str | None = Field(default=None, max_length=200)
    model_exact_variant: str | None = Field(default=None, max_length=200)
    quantity: int | None = Field(default=None, ge=1, le=10000)
    physical_status: str | None = Field(default=None, pattern=r"^(RECEIVED|ORDERED|NOT_BOUGHT|UNKNOWN)$")
    purchase_link_reference: str | None = Field(default=None, max_length=1000)
    photo_reference: str | None = Field(default=None, max_length=1000)
    storage_location: str | None = Field(default=None, max_length=200)
    notes: str | None = Field(default=None, max_length=1000)


class InventoryReviewRequest(BaseModel):
    model_config = ConfigDict(extra="forbid")
    expected_revision: int = Field(ge=0)
    controller_ownership: str | None = Field(default=None, pattern=r"^(ESP32|STM32|HOST|PASSIVE|PROTECTED_SAFETY|UNKNOWN)$")
    function: str | None = Field(default=None, max_length=1000)
    interface_documented: str | None = Field(default=None, max_length=1000)
    voltage_documented: str | None = Field(default=None, max_length=1000)
    current_documented: str | None = Field(default=None, max_length=1000)
    voltage_measured: str | None = Field(default=None, max_length=1000)
    current_measured: str | None = Field(default=None, max_length=1000)
    connector: str | None = Field(default=None, max_length=1000)
    zie_logical_slot: str | None = Field(default=None, max_length=1000)
    driver_extension: str | None = Field(default=None, max_length=1000)
    hardware_profile_mapping: str | None = Field(default=None, max_length=1000)
    cad_status: str | None = Field(default=None, pattern=r"^(CANDIDATE|PARAMETRIC|MEASUREMENT_REQUIRED|MATCH_REVIEW_REQUIRED|MATCHED|MISMATCH|BLOCKED|NOT_APPLICABLE)$")
    dimensions_documented: str | None = Field(default=None, max_length=1000)
    dimensions_measured: str | None = Field(default=None, max_length=1000)
    weight_documented: str | None = Field(default=None, max_length=1000)
    weight_measured: str | None = Field(default=None, max_length=1000)
    safety_criticality: str | None = Field(default=None, max_length=1000)
    verify_on_arrival: str | None = Field(default=None, pattern=r"^(yes|no|UNKNOWN)$")
    decision_keep_replace_undecided: str | None = Field(default=None, pattern=r"^(KEEP|REPLACE|UNDECIDED)$")
    evidence_source: str | None = Field(default=None, max_length=1000)
    reviewer: str | None = Field(default=None, max_length=200)
    review_date: str | None = Field(default=None, max_length=100)
    review_state: str | None = Field(default=None, pattern=r"^(NOT_REVIEWED|REVIEW_REQUIRED|REVIEWED|CONFLICT)$")
    evidence_state: str | None = Field(default=None, pattern=r"^(UNKNOWN|CLAIMED|ORDERED|RECEIVED|PHOTO_AVAILABLE|MODEL_IDENTIFIED|DOCUMENTATION_FOUND|MEASURED|REVIEW_REQUIRED|REVIEWED|VERIFY_ON_ARRIVAL|CONFLICT)$")
    candidate_match: str | None = Field(default=None, pattern=r"^(NONE|NO_CANDIDATE|POSSIBLE_MATCH|MATCH_REVIEW_REQUIRED|MATCHED|MISMATCH|CONFLICT)$")
    driver_state: str | None = Field(default=None, pattern=r"^(NOT_STARTED|BLOCKED_ON_IDENTITY|BLOCKED_ON_DATASHEET|BLOCKED_ON_INTERFACE|BLOCKED_ON_MEASUREMENT|READY_FOR_IMPLEMENTATION|IMPLEMENTED|COMMISSIONING_REQUIRED)$")
    commissioning_dependencies: list[str] | None = Field(default=None, max_length=32)
    measurement_requirements: list[str] | None = Field(default=None, max_length=32)
    conflict_reason: str | None = Field(default=None, max_length=1000)
    candidate_reference: str | None = Field(default=None, max_length=1000)
    mismatch_reason: str | None = Field(default=None, max_length=1000)
    subsystem: str | None = Field(default=None, max_length=100)
    decision_reason_code: str | None = Field(default=None, pattern=r"^(|EXACT_VARIANT_MISMATCH|ELECTRICAL_INCOMPATIBILITY|MECHANICAL_INCOMPATIBILITY|INTERFACE_INCOMPATIBILITY|SAFETY_CONCERN|INSUFFICIENT_PERFORMANCE_EVIDENCE|UNAVAILABLE_DOCUMENTATION|DUPLICATE_UNNEEDED_COMPONENT|SUPERSEDED_DESIGN)$")
    decision_notes: str | None = Field(default=None, max_length=1000)
    protection_dependency: str | None = Field(default=None, max_length=1000)
    electrical_blocker: str | None = Field(default=None, max_length=1000)
    mechanical_blocker: str | None = Field(default=None, max_length=1000)
    implementation_blocker: str | None = Field(default=None, max_length=1000)
    mounting_geometry: str | None = Field(default=None, max_length=1000)
    connector_cable_exit: str | None = Field(default=None, max_length=1000)
    request_verification: bool = False


class RevisionRequest(BaseModel):
    model_config = ConfigDict(extra="forbid")
    expected_revision: int = Field(ge=0)


def create_app(
    settings: Settings | None = None,
    runtime_adapter: HostRuntimeAdapter | None = None,
    inventory_root: Path | None = None,
) -> FastAPI:
    cfg = settings or load_settings()
    auth = BearerAuth(cfg.auth_token)
    events = EventBus()
    robot = RobotController(simulator=cfg.simulator)
    adapter = runtime_adapter or (
        SimulatorRuntimeAdapter(robot) if cfg.simulator else UnavailableRuntimeAdapter(robot)
    )
    initial_runtime = adapter.status()
    if cfg.simulator and initial_runtime.target_mode is not TargetMode.SIMULATION:
        raise ValueError("simulator configuration requires the simulation adapter")
    if not cfg.simulator and initial_runtime.target_mode is TargetMode.SIMULATION:
        raise ValueError("non-simulator configuration cannot use simulation authority")
    state = StateCore(cfg.simulator)
    state.update("robot", {
        "state": initial_runtime.robot_state,
        "target_mode": initial_runtime.target_mode.value,
        "authority": "available" if initial_runtime.authority_generation > 0 else "unavailable",
        "execution": initial_runtime.execution,
        "physically_confirmed": initial_runtime.physically_confirmed,
    })
    audit = AuditLog(cfg.log_path)
    voice = VoiceService(
        cfg.voice_id,
        elevenlabs_synthesizer(cfg.elevenlabs_api_key) if cfg.elevenlabs_api_key else None,
        command_synthesizer(cfg.voice_fallback_command) if cfg.voice_fallback_command else None,
        cfg.elevenlabs_model,
    )
    transcriber = LocalTranscriber()
    preview = WorkspacePreview(cfg.simulator)
    inventory = InventoryStore(inventory_root or (REPOSITORY_ROOT / "runtime" / "inventory"), inventory_schema())

    def runtime_status():
        return adapter.status()

    def real_runtime_ready(current) -> bool:
        return (
            current.target_mode is TargetMode.FUTURE_REAL_TARGET
            and current.readiness == "ready"
            and current.availability == "available"
            and current.authority_generation > 0
            and bool(current.session_id)
        )

    def response_is_consistent(result, before, after, *, allow_requested: bool = False) -> bool:
        if (
            result.authority_generation != after.authority_generation
            or result.target_mode is not after.target_mode
            or before.authority_generation != after.authority_generation
            or before.session_id != after.session_id
        ):
            return False
        valid_outcome = {
            RequestPhase.REQUESTED: allow_requested and not result.delivered and not result.physically_confirmed,
            RequestPhase.ACCEPTED: result.delivered and not result.physically_confirmed,
            RequestPhase.REJECTED: not result.delivered and not result.physically_confirmed,
            RequestPhase.CONFIRMED: (
                result.target_mode is TargetMode.FUTURE_REAL_TARGET
                and result.delivered
                and result.physically_confirmed
            ),
        }[result.phase]
        if not valid_outcome:
            return False
        if result.target_mode is TargetMode.REAL_TARGET_UNAVAILABLE:
            return not result.delivered and not result.physically_confirmed
        if result.target_mode is TargetMode.SIMULATION:
            return not result.physically_confirmed
        return True

    def response_execution(result) -> str:
        if result.physically_confirmed:
            return "confirmed"
        if result.target_mode is TargetMode.SIMULATION and result.delivered:
            return "simulated"
        if result.delivered:
            return "delivered_unconfirmed"
        return "not_delivered"

    async def deadman_loop():
        while True:
            await asyncio.sleep(0.05)
            before = runtime_status()
            result = adapter.poll()
            if result:
                current = runtime_status()
                if (
                    not response_is_consistent(result, before, current)
                    or (
                        current.target_mode is TargetMode.FUTURE_REAL_TARGET
                        and not real_runtime_ready(current)
                    )
                ):
                    state.update("robot", {
                        "state": "DISCONNECTED",
                        "authority": "unavailable",
                        "execution": "not_delivered",
                        "physically_confirmed": False,
                    })
                    await events.publish("runtime.feedback_rejected", {
                        "reason": "stale_or_inconsistent_authority",
                        "source": current.target_mode.value,
                    })
                    continue
                state.update("robot", {
                    "state": current.robot_state, "last_command": result.public(),
                    "execution": response_execution(result),
                    "physically_confirmed": result.physically_confirmed,
                })
                await events.publish("robot.deadman", result.public())
                audit.write("robot.deadman", command=result.public())

    @asynccontextmanager
    async def lifespan(_: FastAPI):
        task = asyncio.create_task(deadman_loop())
        audit.write("server.started", host=cfg.host, port=cfg.port, simulator=cfg.simulator)
        try:
            yield
        finally:
            task.cancel()
            audit.write("server.stopped")

    app = FastAPI(title="ZI-E Control Center", version=APP_VERSION, lifespan=lifespan, docs_url=None, redoc_url=None)
    app.state.settings = cfg
    app.state.events = events
    app.state.core = state
    app.state.robot = robot
    app.state.runtime_adapter = adapter
    app.state.inventory = inventory
    app.mount("/hud", StaticFiles(directory=Path(__file__).parents[1] / "hud"), name="hud-assets")

    def require_auth(authorization: str | None = Header(default=None)):
        if not auth.valid(authorization):
            raise HTTPException(status_code=status.HTTP_401_UNAUTHORIZED, detail="invalid bearer token")

    @app.get("/", include_in_schema=False)
    def hud():
        return FileResponse(Path(__file__).parents[1] / "hud" / "index.html")

    @app.get("/api/health", dependencies=[Depends(require_auth)])
    def health():
        current = runtime_status()
        providers = app_provider_status(cfg, transcriber.status())
        robot_ready = (
            current.target_mode is TargetMode.SIMULATION
            or real_runtime_ready(current)
        )
        return {
            "version": APP_VERSION,
            "status": "ok" if robot_ready else "blocked",
            "readiness": {
                "app": "ready",
                "required_robot": "ready" if robot_ready else "unavailable",
                "overall": "ready" if robot_ready else "blocked",
            },
            "system": system_metrics(),
            "simulator": cfg.simulator,
            "hermes": {"configured": bool(cfg.hermes_command), "session": cfg.hermes_session},
            "model": cfg.hermes_main_model,
            "voice": {
                "provider": "elevenlabs" if cfg.elevenlabs_api_key else "zi-nanami-command" if cfg.voice_fallback_command else None,
                "voice_id": cfg.voice_id,
                "configured": bool(cfg.elevenlabs_api_key or cfg.voice_fallback_command),
            },
            "stt": {"provider": "local", "model": transcriber.model_name, "status": transcriber.status()},
            "robot": current.public(),
            "providers": providers,
        }

    @app.get("/api/state", dependencies=[Depends(require_auth)])
    def get_state():
        return state.snapshot()

    @app.get("/api/settings", dependencies=[Depends(require_auth)])
    def public_settings():
        return {
            "simulator": cfg.simulator,
            "voice_id": cfg.voice_id,
            "elevenlabs_configured": bool(cfg.elevenlabs_api_key),
            "voice_fallback_configured": bool(cfg.voice_fallback_command),
            "hermes_configured": bool(cfg.hermes_command),
            "hermes_session": cfg.hermes_session,
            "provider_priority": app_provider_status(cfg, transcriber.status()),
        }

    @app.get("/api/runtime", dependencies=[Depends(require_auth)])
    def public_runtime():
        return runtime_status().public()

    @app.get("/api/providers", dependencies=[Depends(require_auth)])
    def providers():
        return {"modalities": app_provider_status(cfg, transcriber.status())}

    @app.get("/api/voice/status", dependencies=[Depends(require_auth)])
    def voice_status():
        providers = app_provider_status(cfg, transcriber.status())
        return {
            "stt": {"state": transcriber.status(), "chain": providers["stt"]},
            "tts": {
                "state": "configured" if cfg.elevenlabs_api_key or cfg.voice_fallback_command else "unavailable",
                "muted": state.snapshot()["voice"]["muted"],
                "speaking": state.snapshot()["voice"]["speaking"],
                "chain": providers["tts"],
            },
            "wake": {"state": "unavailable", "chain": providers["wake"]},
        }

    @app.get("/api/hardware-profile", dependencies=[Depends(require_auth)])
    def hardware_profile():
        current = runtime_status()
        return {
            "status": "unavailable" if current.target_mode is TargetMode.REAL_TARGET_UNAVAILABLE else "not_exposed",
            "profile_id": None,
            "resolution_generation": None,
            "device_rebinding": "explicit-only",
        }

    @app.get("/api/configuration", dependencies=[Depends(require_auth)])
    def configuration():
        return {"status": "not_exposed", "generation": None, "mutable": False}

    @app.get("/api/presentation", dependencies=[Depends(require_auth)])
    def presentation():
        return {"status": "not_exposed", "context": None, "face_pack": None, "sound_pack": None}

    @app.get("/api/diagnostics", dependencies=[Depends(require_auth)])
    def diagnostics():
        current = runtime_status()
        return {
            "runtime": current.public(),
            "event_history_count": len(events.history()),
            "persistence": "not_implemented",
            "physical_commissioning": "required",
        }

    @app.get("/api/control-center", dependencies=[Depends(require_auth)])
    def control_center():
        current = runtime_status()
        provider_state = app_provider_status(cfg, transcriber.status())
        voice_state = "configured" if cfg.elevenlabs_api_key or cfg.voice_fallback_command else "unavailable"
        return cockpit_status(current.public(), provider_state, transcriber.status(), voice_state, preview)

    @app.post("/api/presentation/preview", dependencies=[Depends(require_auth)])
    async def presentation_preview(request: PresentationPreviewRequest):
        result = preview.set_presentation(request.model_dump())
        await events.publish("presentation.preview", {**result, "physically_confirmed": False})
        return {**result, "physically_confirmed": False}

    @app.post("/api/actuators/commissioning-preview", dependencies=[Depends(require_auth)])
    async def actuator_preview(request: ActuatorPreviewRequest):
        if request.slot not in ACTUATORS:
            raise HTTPException(status_code=422, detail="unknown logical actuator slot")
        try:
            result = preview.commission(request.slot, request.operation, request.speed)
        except (ValueError, RuntimeError) as exc:
            raise HTTPException(status_code=409, detail=str(exc)) from exc
        await events.publish("actuator.commissioning_preview", result)
        return result

    @app.post("/api/drive/preview", dependencies=[Depends(require_auth)])
    async def drive_preview(request: DrivePreviewRequest):
        try:
            result = preview.drive_request(request.direction, request.speed_limit, request.deadman)
        except ValueError as exc:
            raise HTTPException(status_code=422, detail=str(exc)) from exc
        await events.publish("drive.preview", result)
        return result

    @app.get("/api/developer", dependencies=[Depends(require_auth)])
    def developer_workspace():
        return {
            "repository": repository_status(),
            "actions": [action.public() for action in developer_actions(cfg.log_path, cfg.hermes_command).values()],
            "arbitrary_commands": False,
            "filesystem_api": False,
            "robot_authority": "NONE",
            "test_history": "current-session-events-only",
        }
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

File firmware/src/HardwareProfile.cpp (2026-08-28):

#include "zie/core/HardwareProfile.hpp"

#include <algorithm>
#include <cctype>
#include <iterator>
#include <limits>

namespace zie::core {
namespace {

void require(const bool present, const char* name, ProfileValidation& result) {
  if (!present) result.missing_required.emplace_back(name);
}

void require_owner(const bool present, const ControllerOwner actual,
                   const ControllerOwner expected, const char* name,
                   ProfileValidation& result) {
  if (present && actual != expected) {
    result.missing_required.emplace_back(std::string(name) + " owner");
  }
}

template <typename T>
bool contains(const std::vector<T>& values, const T& value) {
  return std::find(values.begin(), values.end(), value) != values.end();
}

void add_issue(std::vector<HardwareProfileIssue>& issues,
               const HardwareProfileIssue issue) {
  if (!contains(issues, issue)) issues.push_back(issue);
}

bool valid_key(const std::string& value) {
  if (value.empty() ||
      !std::isalnum(static_cast<unsigned char>(value.front()))) {
    return false;
  }
  return std::all_of(value.begin(), value.end(), [](const unsigned char value) {
    return std::islower(value) || std::isdigit(value) || value == '.' ||
           value == '_' || value == '-';
  });
}

bool begins_with(const std::string& value, const std::string& prefix) {
  return value.compare(0, prefix.size(), prefix) == 0;
}

bool contains_namespace_token(const std::string& value,
                              const std::string& token) {
  std::size_t offset = 0;
  while (offset <= value.size()) {
    const auto end = value.find_first_of("._-", offset);
    const auto size = end == std::string::npos ? value.size() - offset
                                               : end - offset;
    if (value.compare(offset, size, token) == 0 && size == token.size()) {
      return true;
    }
    if (end == std::string::npos) break;
    offset = end + 1;
  }
  return false;
}

bool raw_namespace(const std::string& value) {
  static const std::vector<std::string> forbidden{
      "raw",      "gpio",     "pwm",      "register", "motor",
      "actuator", "setpoint", "safety",   "safety_bypass",
      "can",      "usb",      "com",      "ip",       "discovery"};
  return std::any_of(forbidden.begin(), forbidden.end(),
                     [&value](const std::string& token) {
                       return contains_namespace_token(value, token);
                     });
}

bool known(const HardwareDomain value) {
  switch (value) {
    case HardwareDomain::display:
    case HardwareDomain::camera:
    case HardwareDomain::audio_input:
    case HardwareDomain::audio_output:
    case HardwareDomain::range:
    case HardwareDomain::proximity:
    case HardwareDomain::cliff:
    case HardwareDomain::imu:
    case HardwareDomain::drive:
    case HardwareDomain::arm:
    case HardwareDomain::gripper:
    case HardwareDomain::tool:
    case HardwareDomain::rgb:
    case HardwareDomain::touch:
    case HardwareDomain::power:
    case HardwareDomain::battery:
    case HardwareDomain::network:
      return true;
  }
  return false;
}

bool known(const ProfileRequirement value) {
  switch (value) {
    case ProfileRequirement::required:
    case ProfileRequirement::optional:
      return true;
  }
  return false;
}

bool known(const ProfileCardinality value) {
  switch (value) {
    case ProfileCardinality::exactly_one:
    case ProfileCardinality::zero_or_one:
    case ProfileCardinality::one_or_more:
    case ProfileCardinality::zero_or_more:
      return true;
  }
  return false;
}

bool known(const ProfileOwnership value) {
  switch (value) {
    case ProfileOwnership::registry_managed:
    case ProfileOwnership::protected_safety_core:
      return true;
  }
  return false;
}

bool known(const ProfileSource value) {
  switch (value) {
    case ProfileSource::built_in:
    case ProfileSource::operator_approved:
      return true;
  }
  return false;
}

bool known(const RobotPlatformClass value) {
  switch (value) {
    case RobotPlatformClass::zie_desktop_companion:
      return true;
  }
  return false;
}

bool known(const SemanticConstraintDomain value) {
  switch (value) {
    case SemanticConstraintDomain::variant:
    case SemanticConstraintDomain::placement:
    case SemanticConstraintDomain::performance_class:
    case SemanticConstraintDomain::tool_class:
      return true;
  }
  return false;
}

bool known(const extensions::ExtensionCategory value) {
  switch (value) {
    case extensions::ExtensionCategory::hardware_display:
    case extensions::ExtensionCategory::hardware_camera:
    case extensions::ExtensionCategory::hardware_audio_input:
    case extensions::ExtensionCategory::hardware_audio_output:
    case extensions::ExtensionCategory::hardware_range:
    case extensions::ExtensionCategory::hardware_proximity:
    case extensions::ExtensionCategory::hardware_cliff:
    case extensions::ExtensionCategory::hardware_imu:
    case extensions::ExtensionCategory::hardware_drive:
    case extensions::ExtensionCategory::hardware_motor_driver:
    case extensions::ExtensionCategory::hardware_actuator:
    case extensions::ExtensionCategory::hardware_arm:
    case extensions::ExtensionCategory::hardware_gripper:
    case extensions::ExtensionCategory::hardware_tool:
    case extensions::ExtensionCategory::hardware_power:
    case extensions::ExtensionCategory::hardware_battery:
    case extensions::ExtensionCategory::hardware_rgb:
    case extensions::ExtensionCategory::hardware_touch:
    case extensions::ExtensionCategory::hardware_network:
    case extensions::ExtensionCategory::behavior:
    case extensions::ExtensionCategory::ai_provider:
    case extensions::ExtensionCategory::ai_tool:
    case extensions::ExtensionCategory::voice_stt:
    case extensions::ExtensionCategory::voice_tts:
    case extensions::ExtensionCategory::voice_wakeword:
    case extensions::ExtensionCategory::face_pack:
    case extensions::ExtensionCategory::emotion_pack:
    case extensions::ExtensionCategory::rgb_pack:
    case extensions::ExtensionCategory::sound_pack:
    case extensions::ExtensionCategory::automation:
    case extensions::ExtensionCategory::integration:
      return true;
  }
  return false;
}
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

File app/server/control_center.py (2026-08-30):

from __future__ import annotations

import asyncio
from copy import deepcopy
import csv
from dataclasses import asdict, dataclass
from functools import lru_cache
import importlib.util
import io
import json
from pathlib import Path
import re
import shutil
import subprocess
import sys
from threading import RLock
import time
from typing import Any

from app.security.redaction import redact_text
from app.version import APP_STAGE, APP_VERSION
from app.presence.media import media_capability_status
from app.presence.runtime import unverified_presence_status


REPOSITORY_ROOT = Path(__file__).resolve().parents[2]
INVENTORY_TEMPLATE = REPOSITORY_ROOT / "docs" / "templates" / "PURCHASED_PARTS_INTAKE_TEMPLATE.csv"
PHASE2B2_STATE = "WAITING_FOR_VERIFIED_INPUTS"
ESP32_BUILD_STATUS = REPOSITORY_ROOT / "runtime" / "esp32-generic-build.json"
PROJECT_EVIDENCE = REPOSITORY_ROOT / "docs" / "evidence" / "ZI-E_PROJECT_EVIDENCE.json"
REPOSITORY_STATUS_TTL_SECONDS = 2.0
_repository_cache_lock = RLock()
_repository_cache: tuple[float, dict[str, Any]] | None = None

APP_STATES = (
    "SIMULATED", "DISCONNECTED", "UNAVAILABLE", "NOT_CONFIGURED",
    "NOT_VERIFIED", "VERIFY_ON_ARRIVAL", "REQUESTED", "ACCEPTED",
    "DELIVERED", "PHYSICALLY_CONFIRMED", "FAULT", "COMMISSIONED",
)
EXPRESSIONS = ("neutral", "happy", "curious", "sleepy", "warning")
DRIVE_DIRECTIONS = ("forward", "backward", "left", "right", "stop")
CAMERA_MODES = ("UNAVAILABLE", "TEST_SOURCE", "SIMULATED", "FUTURE_PHYSICAL")

WORKSPACES = (
    "OVERVIEW", "ROBOT", "CAMERA / VISION", "FACE / DISPLAY / RGB",
    "MOTORS / ACTUATORS", "SENSORS", "POWER / BATTERY", "CONTROLLERS",
    "VOICE / PROVIDERS", "HARDWARE INVENTORY", "P1 / CAD", "COMMISSIONING",
    "SAFETY", "PLUGINS / PROFILES", "DIAGNOSTICS", "DEVELOPER",
)

ACTUATORS = (
    "drive.left", "drive.right", "arm.left.shoulder", "arm.right.shoulder",
    "arm.left.elbow", "arm.right.elbow", "arm.left.wrist", "arm.right.wrist",
    "gripper.left", "gripper.right", "head.pan", "head.tilt", "head.lift",
    "arm.left.telescope", "arm.right.telescope",
)

SENSORS = (
    "range.head", "cliff.downward.*", "proximity.horizontal.*",
    "bumper.contact.*", "imu.body", "drive.encoder.*", "power.*",
)

COMMISSIONING_GATES = (
    "physical_inventory_reconciled", "mechanical_inspection",
    "continuity_short_check", "logic_only_power", "esp32_boot", "stm32_boot",
    "controller_identity_session", "communications", "sensors_one_by_one",
    "one_restrained_actuator", "direction_range_feedback",
    "safe_stop_verification", "display_audio_camera", "constrained_drivetrain",
    "integrated_restrained_test", "supervised_motion",
)


def _git(*arguments: str) -> str | None:
    try:
        result = subprocess.run(
            ["git", "-c", f"safe.directory={REPOSITORY_ROOT.as_posix()}", *arguments],
            cwd=REPOSITORY_ROOT, capture_output=True, text=True, timeout=3,
            check=False, shell=False,
        )
    except (OSError, subprocess.SubprocessError):
        return None
    return result.stdout.strip() if result.returncode == 0 else None


def _repository_status_uncached() -> dict[str, Any]:
    porcelain = _git("status", "--short", "--branch")
    head = _git("rev-parse", "HEAD")
    recent = _git("log", "-5", "--pretty=format:%h %s")
    diff = _git("diff", "--stat")
    status_lines = porcelain.splitlines() if porcelain is not None else []
    branch_line = status_lines[0] if status_lines and status_lines[0].startswith("## ") else ""
    branch = branch_line[3:].split("...")[0].strip() if branch_line else None
    if branch == "HEAD (no branch)":
        branch = None
    changes = status_lines[1:] if branch_line else status_lines
    return {
        "path": str(REPOSITORY_ROOT),
        "available": head is not None,
        "branch": branch,
        "head": head,
        "short_head": head[:7] if head else None,
        "working_tree": "dirty" if changes else "clean" if porcelain is not None else "unavailable",
        "status": changes,
        "diff_summary": diff.splitlines() if diff else [],
        "recent_log": recent.splitlines() if recent else [],
    }


def clear_repository_status_cache() -> None:
    global _repository_cache
    with _repository_cache_lock:
        _repository_cache = None
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

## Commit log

2026-08-23 v 0.3
    [FMEA_CAD.csv, ZI-E_v1_1_ACTIVE.step, ZI-E_v1_1_CUTAWAY.step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]
2026-08-23 some bug fixed v 0.3
    [FMEA_CAD.csv, ZI-E_v0_3_ACTIVE.step, ZI-E_v0_3_CUTAWAY.step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]
2026-08-24 lite 0.1
    [BATTERY_CARRIER.dxf, BOARD_CARRIER.dxf, BODY_BOTTOM.dxf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]
2026-08-27 feat: add fail-closed device identity foundation
2026-08-28 fix: fail closed when real robot adapter is unavailable
    [main.py]
2026-08-28 docs: complete prototype p1 build-ready package
    [PURCHASED_PARTS_INTAKE_TEMPLATE.csv]
2026-08-30 feat: ingest real hardware inventory evidence
    [Zi-E_Hardware_Master_Inventory.canonical.csv]
2026-08-30 feat: build ESP32 presence and Control Center foundations
2026-08-30 feat: cross-build generic ESP32-S3 presence target
2026-08-30 feat: harden Control Center and reconcile project evidence
    [2026-08-29-Zi-E_Hardware_Master_Inventory.canonical.csv, BATTERY_CARRIER.dxf, BOARD_CARRIER.dxf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]
